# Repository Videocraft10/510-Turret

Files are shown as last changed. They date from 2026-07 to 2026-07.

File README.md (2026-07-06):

# The Soupinator 510

Shenzhen, Fallout
IRL Hackathon Project

This project is an auto tracking turret featuring a laser. It uses four different servos in order to control the pitch and yaw of a 3D printed turret.

The reason this project was made is because THE WORLD IS ENDING!!!! and soup needs a way to annihilate his enemies and protect himself from the vicious beasts of an apocolyptic world. For this reason, we have created the SOUPINATOR 510, a havoc-wreaking turret that will mow down anyone in soup's path.

We built this using 3D modeled parts and by working around components not readily available. For example, we did not have a lazy susan, so we got around that by using herringbone gears with edge blocks to hold a large gear in place with two other gears, essentially making a floating gear.

Promo Video: [here](https://youtu.be/GHd5qp_cuug)

[Zine.pdf](https://github.com/user-attachments/files/29722932/Zine.pdf)

### Disclaimer 

Although we wished to use the XIAO ESP32 Sense camera to track movement, due to a difference in available library version and the ESP32 version, we were forced to use a laptop camera

## Build Instructions

First, please make sure you have all the parts printed. They are made to look best in black.
You should have:
* Left Turret Sideplate
* Right Turret Sideplate
* Turret Head
* Base
* Central Gear
* Servo Gear (2)
* Legs (3)

Then, Please gather the following parts:
* MG90S (2)
* MG995 (2)
* Cross-shaped servo horn (2)
* Circular servo horn (2)
* XIAO ESP32 Sense (Optional)
* XIAO ESP32-C3
* Laser module
* Assorted screws, bolts, and washers (and heatset inserts if you want to be fancy!)

Take the MG90S servos and screw them in (wire first) into the rectangular cutouts on the Left and Right Turret Sideplates (The horn should be facing into the side with no lettering)



Attach the cross shaped horn to the each side Turret head, then attach both of the Turret sides to that assembly using the servo horns.

Attach the laser to the bottom of the Turret head using zipties. Optionally attach the Sense to the extrusion on the side of the Turret head using screws.



The top of the turret is complete.

For the bottom of the turret, attach the legs to the base using screws. Everything should line up. 



Then, slide the MG995 servos into the servo slots, and screw them in.

Take each smaller servo gear, and attach the circular servo horn on the underside, with side connecting to the servo on the bottom. Use screws.

Attach ONE of those small gears onto one of the MG995 servos. Then, align the Central Gear with that smaller gear, and roll it until you are able to attach the second smaller gear.



The bottom part of the turret is complete!

To attach them, screw the bottom of the Turret sidplates (there are holes) into the Central Gear. 



## Electrical
Wire according to the wiring diagram. Use power from either a laptop (or recommended) a spliced usb cable to a plug.
Schematic

## Firmware
AI Tracking Turret

Face-tracking pan/tilt turret. Mac webcam does vision processing, XIAO ESP32-C3 drives servos + laser over USB serial.

Requirements

macOS, Windows, or Linux
Python 3.10+
Arduino IDE 2.0+
XIAO ESP32-C3
4x servo (2 pan, 2 tilt) + laser diode

1. Firmware setup (XIAO ESP32-C3)

Install Arduino IDE
Arduino IDE → Settings → Additional Boards Manager URLs:

   https://raw.githubusercontent.com/espressif/arduino-esp32/gh-pages/package_esp32_index.json

Boards Manager → search esp32 → install latest (Espressif Systems)
Connect XIAO C3 via USB-C → select board XIAO_ESP32C3 and the matching port
Paste in the C3 firmware (c3.ino)
Verify it first, then Upload it
Open Serial Monitor at 115200 baud to confirm it's running

2. Host software setup (Python)

bashpython3 --version          # confirm Python 3.10+
pip3 install opencv-python mediapipe pyserial

Open the tracking script and set SERIAL_PORT to match your board:

macOS: /dev/cu.usbmodemXXXX
Windows: COM3 (or similar)

Get the exact value from Arduino IDE's port dropdown.

3. Running it

Confirm XIAO C3 is wired (servos/laser powered from power bank, common ground with C3 — see wiring diagram) and connected to your Mac via USB-C
Close Arduino Serial Monitor (it locks the port)
Run:

Paste in the python camera code (soupinator.py)

bash   python3 soupinator.py

A webcam window opens — step into frame, servos should track your face, laser lights up on lock

Troubleshooting

Port busy: lsof | grep usbmodem<port>, kill the PID holding it
No servo movement: confirm Serial Monitor is closed, check FRAME_W/FRAME_H in firmware match your webcam resolution
Wrong pan direction: check cv2.flip() mirroring matches your coordinate mapping
Gear strain: lower MAX_STEP in firmware to slow servo response

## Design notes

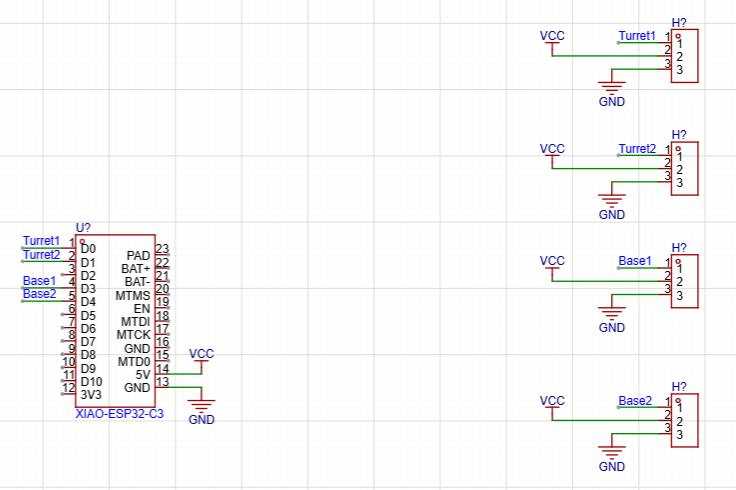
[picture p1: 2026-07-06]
Wiring/Schematic.png

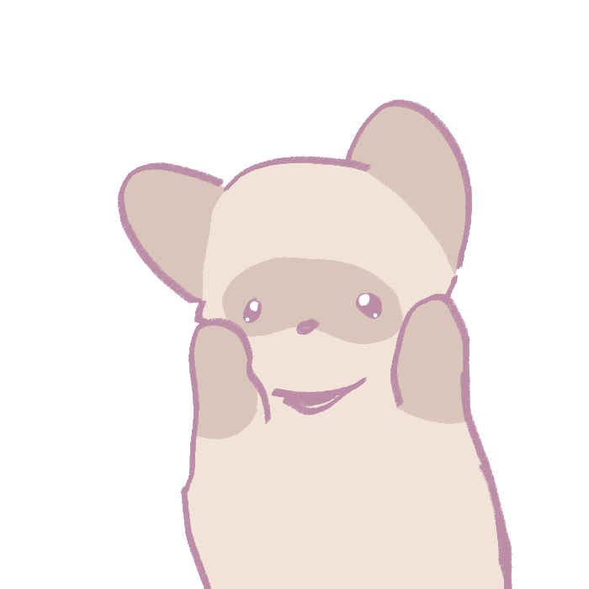
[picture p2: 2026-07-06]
Promo/thnak youuuuu.png

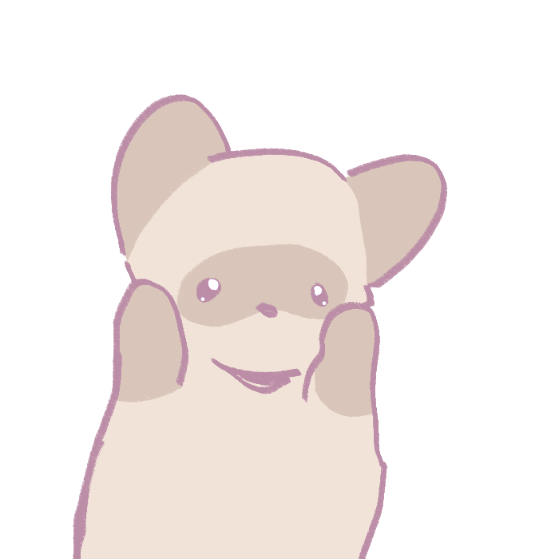
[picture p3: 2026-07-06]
Promo/thnak youuuuuFLIP.png

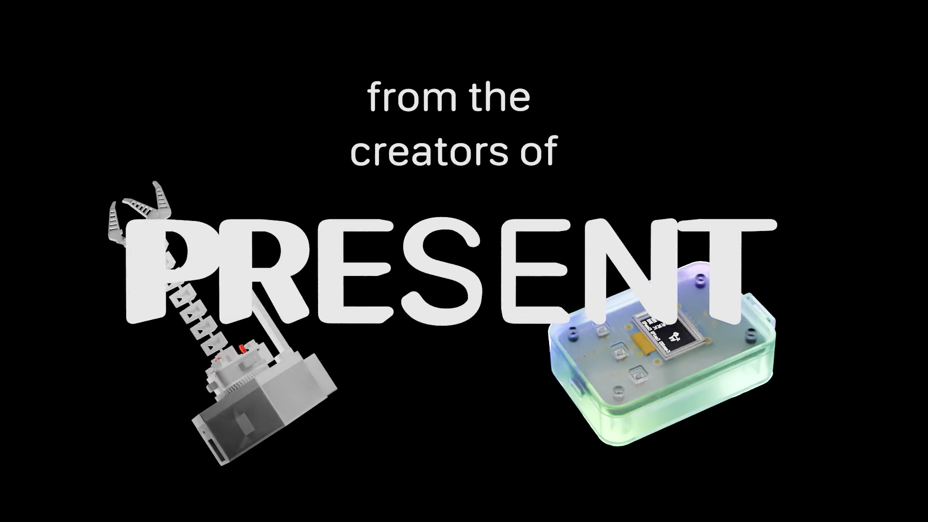
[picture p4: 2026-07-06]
Promo/Video/Footage/Present sc.jpg

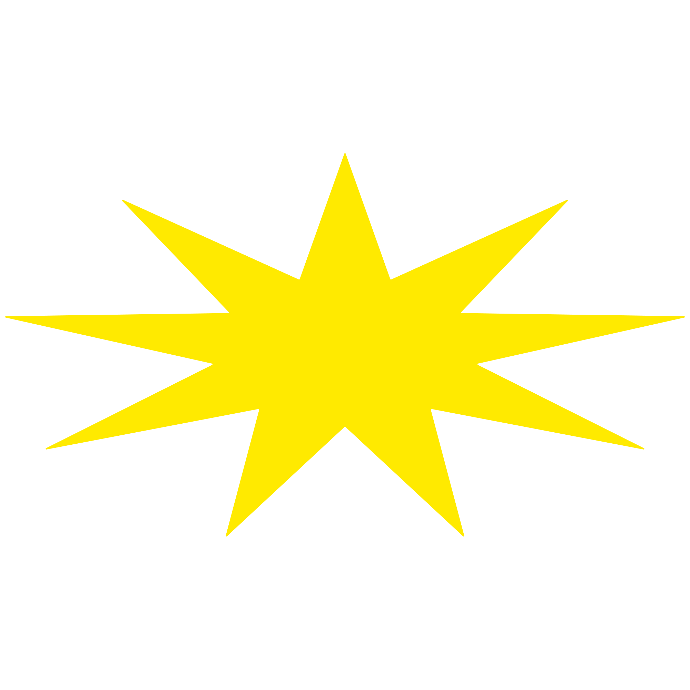
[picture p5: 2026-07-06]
Promo/Video/Footage/StarBub.png

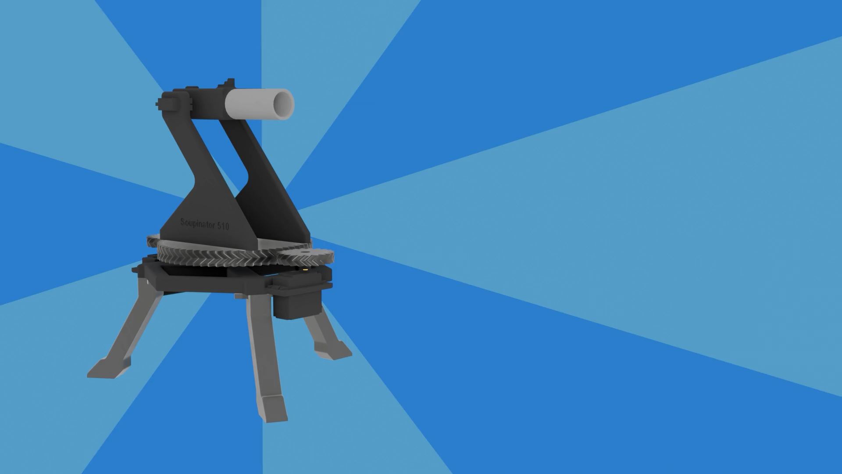
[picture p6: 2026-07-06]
Promo/Video/Footage/endframehold.jpg

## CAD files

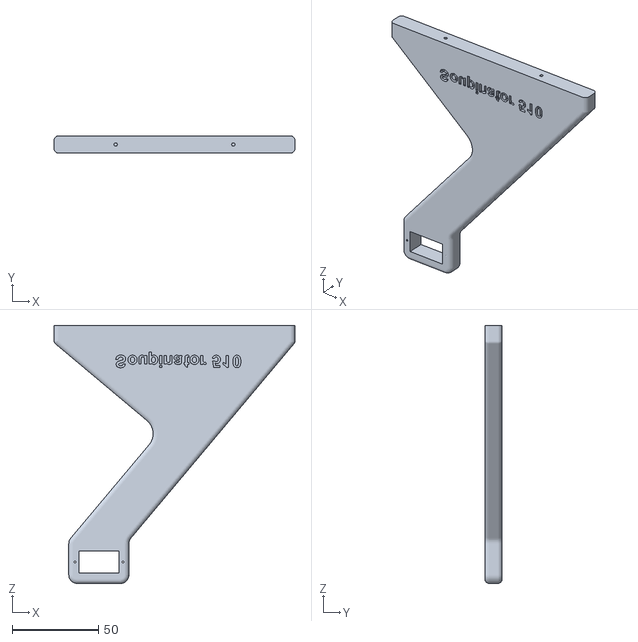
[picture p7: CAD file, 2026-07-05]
CAD/Parts/Left_Turret_Sideplate.stl
140.0 x 10.0 x 150.0

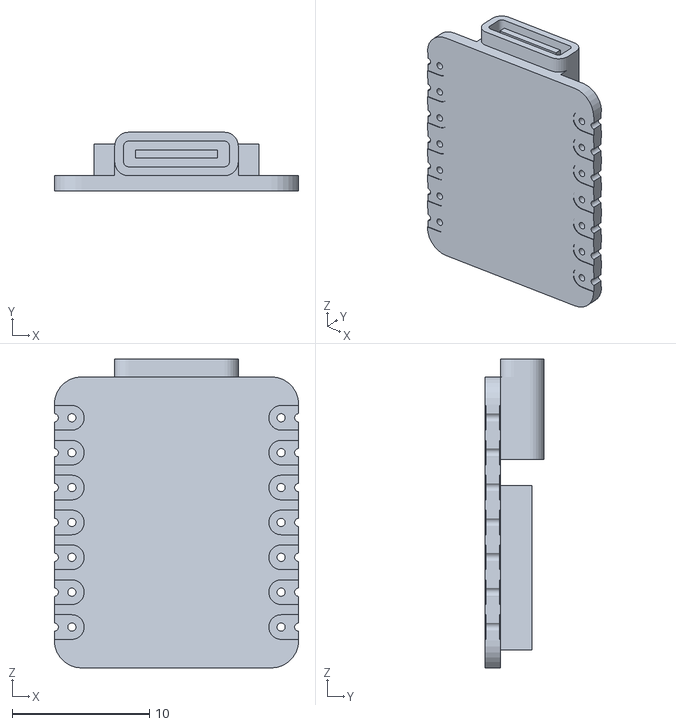
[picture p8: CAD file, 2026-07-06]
Promo/Video/model-Seeeduino_Xiao_v2.stl
17.8 x 4.27 x 22.5

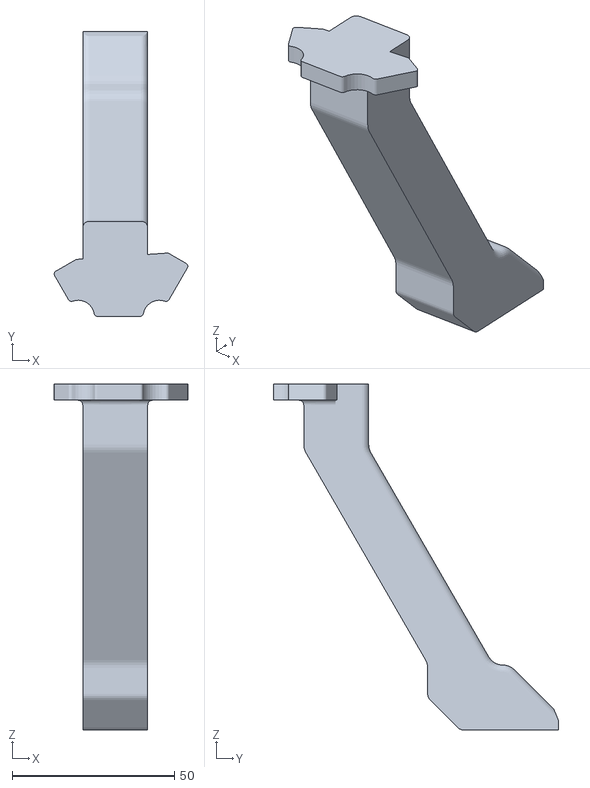
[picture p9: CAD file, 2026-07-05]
CAD/Parts/Leg.stl
41.1 x 87.7 x 106.5

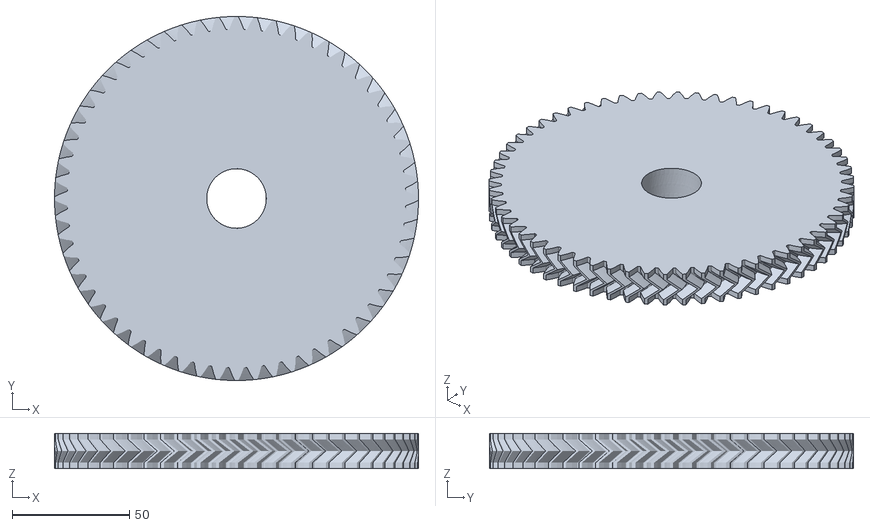
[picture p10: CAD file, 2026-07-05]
CAD/Parts/Central_Gear.stl
155.0 x 155.0 x 15.0

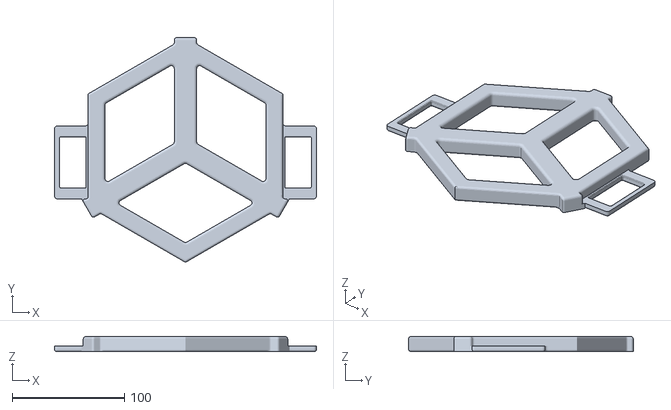
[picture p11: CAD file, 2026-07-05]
CAD/Parts/Base.stl
233.2 x 200.0 x 13.5

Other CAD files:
CAD/Parts/Right_Turret_Sideplate.stl
Promo/Video/Edit/Blender/510 Turret Specs LAPTOP.blend

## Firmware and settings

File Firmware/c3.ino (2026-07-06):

#include <ESP32Servo.h>

// --- RAW NATIVE GPIO PIN CONFIGURATION ---
#define PAN1_PIN 2    // Physical Pin IO2
#define PAN2_PIN 3    // Physical Pin IO3
#define TILT1_PIN 5   // Physical Pin IO5
#define TILT2_PIN 6   // Physical Pin IO6
#define LASER_PIN 4   // Physical Pin IO4

Servo pan1, pan2, tilt1, tilt2;
float panAngle = 90.0, tiltAngle = 90.0;

const int FRAME_W = 320, FRAME_H = 240;
const int DEADZONE = 8;
const float GAIN = 0.08;
const float SMOOTH = 0.35; 

float smoothCx = FRAME_W / 2.0, smoothCy = FRAME_H / 2.0;
unsigned long lastValid = 0;
const unsigned long LOST_TIMEOUT = 800; 

void setup() {
  // Your board handles the direct MacBook USB cable using standard Serial natively!
  Serial.begin(115200);
  Serial.setTimeout(5); 
  
  // Bind physical servo motors to designated GPIO channels
  pan1.attach(PAN1_PIN);
  pan2.attach(PAN2_PIN);
  tilt1.attach(TILT1_PIN);
  tilt2.attach(TILT2_PIN);
  
  // Designate tracking laser connection
  pinMode(LASER_PIN, OUTPUT);
  digitalWrite(LASER_PIN, LOW); // Safe startup default
  
  // Drive hardware gimbals immediately to standard 90-degree central idle targets
  pan1.write((int)panAngle);
  pan2.write((int)panAngle);
  tilt1.write((int)tiltAngle);
  tilt2.write((int)tiltAngle);
}

void loop() {
  // Read incoming packets from the default serial stream
  if (Serial.available()) {
    String line = Serial.readStringUntil('\n');
    int cx, cy, area;
    
    // Parse out incoming tracking payload string
    if (sscanf(line.c_str(), "%d,%d,%d", &cx, &cy, &area) == 3) {
      
      // Apply linear interpolation smoothing logic
      smoothCx = smoothCx + SMOOTH * (cx - smoothCx);
      smoothCy = smoothCy + SMOOTH * (cy - smoothCy);
      lastValid = millis(); // Reset safety timeout watchdog clock
      
      // Determine displacement boundaries relative to center crosshair
      int errX = smoothCx - FRAME_W / 2;
      int errY = smoothCy - FRAME_H / 2;
      
      // Update orientation trajectories only if outside defined structural deadzones
      if (abs(errX) > DEADZONE) panAngle -= errX * GAIN;
      if (abs(errY) > DEADZONE) tiltAngle += errY * GAIN;
      
      // Enforce physical travel limits to eliminate mechanical binding/stalling
      panAngle = constrain(panAngle, 0, 180);
      tiltAngle = constrain(tiltAngle, 30, 150);
      
      // Update hardware positions
      pan1.write((int)panAngle);
      pan2.write((int)panAngle);
      tilt1.write((int)tiltAngle);
      tilt2.write((int)tiltAngle);
      
      // Engage laser target indicator
      digitalWrite(LASER_PIN, HIGH);
    }
  }
  
  // CRITICAL FAILSAFE WATCHDOG: Disengage laser immediately if target tracking halts
  if (millis() - lastValid > LOST_TIMEOUT) {
    digitalWrite(LASER_PIN, LOW);
  }
}

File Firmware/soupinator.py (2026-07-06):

#use this for 16 error: lsof | grep usbmodem101

# import cv2
# import serial
# import time
# import sys

# # --- CONFIGURATION ---
# SERIAL_PORT = "/dev/cu.usbmodem101" 
# BAUD = 115200
# SEND_INTERVAL = 0.04  # Speed up slightly to 40ms for higher tracking response

# try:
#     ser = serial.Serial(SERIAL_PORT, BAUD, timeout=1)
#     time.sleep(2)
# except Exception:
#     sys.exit(1)

# # Load both Frontal and Profile face tracking architectures
# face_cascade = cv2.CascadeClassifier(cv2.data.haarcascades + "haarcascade_frontalface_default.xml")
# profile_cascade = cv2.CascadeClassifier(cv2.data.haarcascades + "haarcascade_profileface.xml")

# cap = cv2.VideoCapture(0, cv2.CAP_AVFOUNDATION)
# last_send = 0


# while True:
#     ret, frame = cap.read()
#     if not ret: continue
    
#     frame = cv2.flip(frame, 1)  # Natural mirror mapping
#     frame = cv2.resize(frame, (320, 240))
#     gray = cv2.cvtColor(frame, cv2.COLOR_BGR2GRAY)
    
#     # Execute primary frontal scan with strict noise filtering
#     faces = face_cascade.detectMultiScale(gray, scaleFactor=1.1, minNeighbors=10, minSize=(60, 60))
#     tracking_mode = "FRONT LOCK"
    
#     # Pass 2: Right Profile & Up/Down Tilt Scan (Loosened thresholds for better vertical tracking)
#     if len(faces) == 0:
#         faces = profile_cascade.detectMultiScale(gray, scaleFactor=1.05, minNeighbors=5, minSize=(60, 60))
#         tracking_mode = "PROFILE RIGHT LOCK"
        
#     # Pass 3: Left Profile Scan (Tricks OpenCV by flipping the image horizontally in memory)
#     if len(faces) == 0:
#         flipped_gray = cv2.flip(gray, 1)
#         left_faces = profile_cascade.detectMultiScale(flipped_gray, scaleFactor=1.05, minNeighbors=5, minSize=(60, 60))
        
#         if len(left_faces) > 0:
#             # Mathematical inversion to map the coordinates back onto your normal screen space
#             for (lx, ly, lw, lh) in left_faces:
#                 cx_flipped = lx + lw // 2
#                 cx_normal = 320 - cx_flipped
#                 x = cx_normal - lw // 2
#                 y = ly
#                 w = lw
#                 h = lh
#             faces = [(x, y, w, h)]
#             tracking_mode = "PROFILE LEFT LOCK"
        
#     now = time.time()
#     if now - last_send > SEND_INTERVAL:
#         if len(faces) > 0:
#             x, y, w, h = max(faces, key=lambda f: f[2] * f[3])
#             cx, cy = x + w // 2, y + h // 2
#             area = w * h
            
#             # Send live tracking packet
#             ser.write(f"{cx},{cy},{area}\n".encode())
            
#             # Draw green indicator box around the target
#             cv2.rectangle(frame, (x, y), (x + w, y + h), (0, 255, 0), 2)
#             cv2.circle(frame, (cx, cy), 4, (0, 0, 255), -1)
#             cv2.putText(frame, tracking_mode, (x, y - 10), cv2.FONT_HERSHEY_SIMPLEX, 0.4, (0, 255, 0), 1)
#         else:
#             # Send lost notice (Arduino memory buffer handles position hold)
#             ser.write(b"0,0,0\n")
            
#         ser.flush()
#         last_send = now
        
#     # Calibration Crosshair Overlay
#     cv2.line(frame, (160, 110), (160, 130), (255, 255, 255), 1)
#     cv2.line(frame, (150, 120), (170, 120), (255, 255, 255), 1)
    
#     cv2.imshow("Advanced Target Acquisition System", frame)
#     if cv2.waitKey(1) & 0xFF == ord('q'):
#         break

# cap.release()
# cv2.destroyAllWindows()
# ser.close()

import cv2
import mediapipe as mp
import serial
import time
import sys
# --- CONFIGURATION ---
SERIAL_PORT = "/dev/cu.usbmodem101" 
BAUD = 115200
SEND_INTERVAL = 0.03  # Send tracking coordinates every 30ms
# --- PORT HANDLING & HANDSHAKE ---
try:
    ser = serial.Serial(SERIAL_PORT, BAUD, timeout=1)
    time.sleep(2)  # Stabilization delay for ESP32 boot cycle
except Exception as e:
    print(f"\n[!!!] PORT ERROR: Verify that the Arduino Serial Monitor is completely CLOSED! ({e})\n")
    sys.exit(1)
# --- INITIALIZE BLAZEFACE AI PIPELINE ---
mp_face_detection = mp.solutions.face_detection
# model_selection=0 is optimized for short-range camera tracking (< 2 meters)
face_detection = mp_face_detection.FaceDetection(model_selection=0, min_detection_confidence=0.5)
cap = cv2.VideoCapture(0, cv2.CAP_AVFOUNDATION)
last_send = 0
while True:
    ret, frame = cap.read()
    if not ret: 
        continue

    # 1. Flip horizontally so tracking directions mirror your body movements naturally
    frame = cv2.flip(frame, 1)
    frame = cv2.resize(frame, (320, 240))

    # 2. Convert color space from OpenCV default BGR to MediaPipe AI native RGB
    rgb_frame = cv2.cvtColor(frame, cv2.COLOR_BGR2RGB)

    # 3. Process frame through the local neural network
    results = face_detection.process(rgb_frame)

    target_found = False
    cx, cy, area = 0, 0, 0
    largest_area = 0
    best_bbox = None
    # 4. Filter and select target
    if results.detections:
        for detection in results.detections:
            # Extract proportional bounding markers from the model
            bboxC = detection.location_data.relative_bounding_box

            # Map proportional floats to explicit 320x240 pixel grids
            w = int(bboxC.width * 320)
            h = int(bboxC.height * 240)
            x = int(bboxC.xmin * 320)
            y = int(bboxC.ymin * 240)

            current_area = w * h

            # Filter noise and lock onto the single largest target in view
            if current_area > largest_area and w > 30 and h > 30:
                largest_area = current_area
                cx = x + w // 2
                cy = y + h // 2
                area = current_area
                best_bbox = (x, y, w, h)
                target_found = True
    # 5. Serial Transmission
    now = time.time()
    if now - last_send > SEND_INTERVAL:
        if target_found and best_bbox is not None:
            # Transmit standard coordinate packet to the ESP32
            ser.write(f"{cx},{cy},{area}\n".encode())

            # UI: Bounding box, target lock indicator, and tracking dot
            bx, by, bw, bh = best_bbox
            cv2.rectangle(frame, (bx, by), (bx + bw, by + bh), (0, 255, 0), 2)
        else:
            # Send standard lost packet so the hardware halts tracking safely
            ser.write(b"0,0,0\n")

        ser.flush()
        last_send = now

    cv2.imshow("Target Acquisition System", frame)
    if cv2.waitKey(1) & 0xFF == ord('q'):
        break
# Clean termination to prevent serial port locking on subsequent runs
face_detection.close()
cap.release()
cv2.destroyAllWindows()
ser.close()

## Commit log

2026-07-05 Cad files added
2026-07-05 file organization
    [Base.stl, Central_Gear.stl, Left_Turret_Sideplate.stl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]
2026-07-06 Submission video part 1
    [510 Turret Specs LAPTOP.blend, model-Seeeduino_Xiao_v2.stl]
2026-07-06 Document AI Tracking Turret setup in README
    Added instructions for setting up AI Tracking Turret with XIAO ESP32-C3 and Python.
